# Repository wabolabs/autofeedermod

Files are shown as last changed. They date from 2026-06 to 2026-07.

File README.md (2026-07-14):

# Autofeeder Controller

Drop-in PCB replacement for a timed chicken feed dispenser. ESP32-C6 based with Matter/ESPHome, local standalone operation, motor control, CAN bus, RTC timekeeping, and optional GPS sync.

## Features

- **MCU**: ESP32-C6-Zero (Matter, WiFi 6, Thread, BLE 5) — socketed via 2×9 2.54mm headers + 7 pogo pins
- **Display**: SSD1306 128×64 SPI OLED with full menu system (status, schedules, settings, GPS, manual feed)
- **Motor**: DRV8871 H-bridge for 4VDC auger motor
- **Power**: 18650 Li-ion with TP4056 charger + DW01A/FS8205A battery protection + TPS63031 buck-boost to 3.3V
- **RTC**: DS3231 module (I2C) with CR2032 backup for offline timekeeping
- **GPS**: NEO-6M/8M module header (UART) for offline RTC time sync
- **CAN Bus**: SN65HVD230 via USB-C SBU pins
- **USB-C**: 5V charging + CAN sideband on SBU pins
- **Buttons**: 6 tactile switches (GP0–GP5) for menu navigation
- **Standalone operation**: Schedules stored in NVS, RTC keeps time without network, full local control via screen and buttons

## Project Structure

```
hardware/kicad/          — KiCad design files (generated)
  ├── autofeeder.kicad_sch      — Generated schematic
  ├── autofeeder.kicad_pcb      — Generated PCB (autorouted + verified)
  ├── autofeeder.kicad_pro      — KiCad project settings
  ├── sheet_specs/autofeeder.py — Python schematic generator
  └── autofeeder_pcb.py         — Python PCB pipeline (place, route, pour, verify, export)
hardware/symbols/         — Custom KiCad symbol library
hardware/footprints/      — Custom KiCad footprints (ESP32-C6-Zero socket, OLED module)
firmware/esphome/         — ESPHome configuration
docs/                     — BOM, pinout, mechanical specs
fabrication/              — Gerbers, drill, BOM, CPL (for JLCPCB)
tools/sch_gen/            — KiCad S-expression generation library
```

## Pin Assignments

See [docs/pinout.md](docs/pinout.md) for full GPIO table.

Key assignments:
- GP0–GP5: Buttons (individual GPIOs)
- GPIO19/20: Motor control (TX/RX repurposed)
- GP14/15/18/12: Display SPI (DC on GP12 via pogo pin)
- GP21/22: CAN bus
- GP6: Battery monitor ADC
- GP13/23: I2C for DS3231 RTC
- GP7/8: UART for GPS module

## Standalone Operation

The controller runs independently of Home Assistant/ESPHome:

- **RTC**: DS3231 keeps time with coin cell backup during power loss
- **Schedules**: Up to 4 daily feeding times stored in ESP32 NVS
- **Display**: Full menu system — status, manual feed, schedule list, time set, GPS status, settings
- **Buttons**: POWER (back), TIMER (cycle), MANUAL (feed), SETTINGS (confirm/toggle), UP/DOWN (adjust)
- **GPS**: Optional module for offline time synchronization
- **Matter**: When network is available, schedules can also be managed via Home Assistant

## Build

### Schematic
```bash
PYTHONPATH=tools python3 hardware/kicad/sheet_specs/autofeeder.py
```

### PCB
```bash
# Requires KiCad 9.0+ and Freerouting on PATH
PYTHONPATH=tools python3 hardware/kicad/autofeeder_pcb.py
```

### Firmware
```bash
cd firmware/esphome
esphome run autofeeder.yaml
```

## BOM

See [docs/bom.md](docs/bom.md) for full bill of materials.

### Required additions (not on main board)
- DS3231 RTC module (ZS-042) with CR2032 cell
- NEO-6M/7M/8M GPS module (optional)
- 7× pogo pins 0.9mm × 11mm (for Zero bottom-edge pads)

## License

CERN Open Hardware Licence Version 2 - Weakly Reciprocal (CERN-OHL-W-2.0)

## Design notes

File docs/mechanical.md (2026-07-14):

# Mechanical Specification — Form-Factor Fit

The new ESP32-C6 board is a **drop-in replacement** for the original **WSG-V1.7** board
and must fit the **existing fascia unchanged**. The electronics are redesigned, but every
mechanical interface below must match the original so it seats in the same enclosure and
lines up with the fascia's button openings and display window.

> **Status: MEASUREMENTS APPLIED (2026-06-05).** Layout rework: motor connectors
> (`J_MOTOR_CTRL1`, `J_MOTOR_PWR1`) moved from default fallback (28,27) to right edge at
> Y=10,Y=21 clustered above BATT (J1 at Y=32); J_RTC1 moved from (28,36) to (42,30) to clear
> SW5 THT pins; Wabo Labs logo added to B.SilkS at (30,36). Connector positions now specified. 
> The board generates, routes (0 unconnected), and exports fab files cleanly.
> 
> DRC: **13 violations (all pre-route clearance — OC_GATE/OD_GATE/L2_NODE vs U1/U4 pads;
> 0 unconnected, 0 courtyard overlaps).** These are the same pre-existing pre-route track
> clearance issues noted in BOM bodge-wire section. No new violations from layout changes.
> Button↔hole courtyard and USB-C `starved_thermal` errors fixed. Silkscreen warnings
> resolved: overlapping reference labels hidden on silk, redundant edge-connector silk
> outlines removed.
>
> **IMPORTANT: ESP32-C6-Zero Programming.** The Waveshare module is **hand-socketed** on 2×9 2.54mm pin headers. The module's **onboard USB-C port** (tucked inside the enclosure) is the ONLY way to program the firmware — open the enclosure, connect USB-C, and use `esptool.py` or the Arduino IDE. The main board's USB-C (J3) is for charging only. The UART pins (TX/RX) are repurposed for motor control on the main board and are NOT connected to the programming header (J4). This choice prioritizes board density; reflashing requires a few minutes of enclosure access.
>
> Remaining JST connector center positions (§3) are still `???` — they were placed along the
> right edge (precision not required per measurement notes); refine if a specific cable exit is needed.

Datum: bottom-left corner of the board = origin (0, 0). X → right, Y → up
(KiCad uses Y-down internally; the script handles the flip).

## 1. Board outline
| Spec | Value | Notes |
|---|---|---|
| Width (X)  | 56 mm | |
| Height (Y) | 54 mm | |
| Corner radius | 0 mm | original corners look slightly rounded |
| PCB thickness | 1.6 mm | standard FR4, 2-layer |
| Any non-rectangular notches/cutouts? | no | e.g. tabs, edge cutouts |

## 2. Mounting holes
| Hole | X (mm) | Y (mm) | Drill Ø (mm) | Pad/annular |
|---|---|---|---|---|
| H1 | 7 | 48 | 2 | |
| H2 | 7 | 11 | 2 | |
| H3 | 48 | 48 | 2 | |
| H4 | 48 | 11 | 2` | |
(Original appears to have holes near the corners — confirm count and positions.)

## 3. Connectors (positions along board edges)
| Ref | Part | Edge | Center X (mm) | Center Y (mm) | Overhang past edge (mm) |
|-----|---|---|---|---|---|
| J3  | USB-C | bottom | 30 | 2.5? | 1 |
| J4  | prog header 1x4 | right | 53 | 39 | |
| J_MOTOR_CTRL1 | JST-XH 2P (MX1508 control) | right | 52 | 10 | |
| J_MOTOR_PWR1 | JST-XH 2P (MX1508 power) | right | 52 | 21 | |
| J1 (battery) | JST-XH 2P | right | 52 | 32 | |

## 4. Buttons (centers — must align with fascia openings)
Original silkscreen: KEY1/KEY2/KEY3 across the top, KEY4/KEY5/KEY6 across the bottom.
| Button | Original label | Center X (mm) | Center Y (mm) |
|---|---|---|---|
| SW1 | KEY1 | 12 | 48 |
| SW2 | KEY2 | 28 | 48 |
| SW3 | KEY3 | 42.5 | 48 |
| SW4 | KEY4 | 12 | 11 |
| SW5 | KEY5 | 28 | 11 |
| SW6 | KEY6 | 42.5 | 11 |

## 5. Display window
The original is a segment LCD; the replacement is an SSD1306 OLED. The OLED **active area**
must sit behind the fascia's existing window.
| Spec | Value | Notes |
|---|---|---|
| Fascia window center X | 28 mm | |
| Fascia window center Y | 30 mm | |
| Fascia window width  | 44 mm | |
| Fascia window height | 26 mm | |
| Display PCB keep-out (if OLED module) | not sure | OLED breakout outline if used |

## 6. Fascia photos
Reference photos are in [reference/](reference/):
- `fascia_front_ruler.jpg` — membrane overlay (button icons + window)
- `fascia_frame_ruler.jpg` — 3D-printed frame (screw bosses, button holes, window rim)
- `board_front_ruler.jpg` / `board_back_ruler.jpg` — original WSG-V1.7 board with ruler
- `originalboard_front.jpeg` / `originalboard_back.jpeg` — original board, close-up

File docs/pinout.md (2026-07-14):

# GPIO Assignment — ESP32-C6-Zero

## Pinout

ESP32-C6-Zero socket pinout per Waveshare diagram. Bottom edge pads accessed via pogo pins.

| GPIO | Function | Destination | Notes |
|---|---|---|---|
| **Buttons (left rail, GP0–GP5)** | | | |
| GP0 | BUTTON_POWER | SW1 to GND | |
| GP1 | BUTTON_TIMER | SW2 to GND | |
| GP2 | BUTTON_MANUAL | SW3 to GND | |
| GP3 | BUTTON_SETTINGS | SW4 to GND | |
| GP4 | BUTTON_UP | SW5 to GND | |
| GP5 | BUTTON_DOWN | SW6 to GND | |
| **Motor (right rail, TX/RX)** | | | |
| GPIO19 (TX) | MOTOR_IN1 | MX1508 IN1 (via J_MOTOR_CTRL) | PWM capable |
| GPIO20 (RX) | MOTOR_IN2 | MX1508 IN2 (via J_MOTOR_CTRL) | PWM capable |
| **Display (right rail + bottom edge)** | | | |
| GP14 | DISP_SCK | OLED SCK | SPI clock |
| GP15 | DISP_MOSI | OLED MOSI | SPI data |
| GP18 | DISP_CS | OLED CS | Chip select |
| GP12 (bottom pad 20) | DISP_DC | OLED DC | Data/command (via pogo pin) |
| — | DISP_RST | Pull-up 10k to 3.3V | No GPIO — R13 holds high |
| **CAN Bus** | | | |
| GP21 | CAN_TX | SN65HVD230 D | TWAI controller TX |
| GP22 | CAN_RX | SN65HVD230 R | TWAI controller RX |
| **Battery Monitor (bottom edge)** | | | |
| GP6 (bottom pad 25) | BAT_MON | Voltage divider 2×10k | ADC-capable, 0–4.2V → 0–2.1V (via pogo pin) |
| **I2C (RTC DS3231)** | | | |
| GP13 (bottom pad 19) | I2C_SDA | DS3231 module SDA | Pogo pin |
| GP23 (bottom pad 21) | I2C_SCL | DS3231 module SCL | Pogo pin |
| **GPS UART** | | | |
| GP7 (bottom pad 24) | GPS_TX | GPS module RX | UART TX output (pogo pin) |
| GP8 (bottom pad 23) | GPS_RX | GPS module TX | UART RX input — strapping, input only (pogo pin) |
| GP9 (bottom pad 22) | CAN_RS | SN65HVD230 RS pin | BOOT strapping — driven LOW at run (CAN high-speed), HIGH in deep sleep (CAN standby ~1µA) |
| **Status LED** | | | |
| GPIO6 | STATUS_LED | LED + 330R → GND | Also available on Zero's onboard WS2812 (GPIO8) |
| **Free GPIOs** | | | |
| GPIO0 | — | — | Strapping (pull-up for boot), used as BUTTON_POWER |
| GPIO3 | — | — | JTAG strapping, used as BUTTON_SETTINGS |
| GPIO8 | — | — | Strapping VDD_SPI, used as GPS_RX (input only) |

## Power Nets

| Net | Source | Destination | Voltage |
|---|---|---|---|
| VBUS | USB-C VBUS | TP4056 VCC, D1 anode | 5V |
| BATT+ | TP4056 BAT | DW01A BATT+, TPS63031 VIN | 3.0–4.2V |
| VCC_3V3 | TPS63031 VOUT | ESP32, OLED, CAN, RTC, GPS, pull-ups | 3.3V |
| GND | Common | All GND | 0V |

## Strapping Pin Notes

- **GPIO0**: Pull-up for normal boot. Button to GND is OK (only sampled at power-up).
- **GPIO3**: JTAG strapping. Avoid using as output (used as input button only).
- **GPIO8**: VDD_SPI voltage select. Used as GPS_RX input only — do not drive externally at boot.
- **GPIO9**: BOOT strapping. Leave NC.

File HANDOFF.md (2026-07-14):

# Handoff — 2026-07-13

## ⚠️ Correction (later 2026-07-13 session)

The claims below about commit `04d4fbc` being "fab-ready" with 3 "pre-existing marginal"
DRC violations were **wrong**. Those 3 violations were **real electrical shorts**, all in
hand-coded pre-routes in `_pre_route_batt_n()`:

1. **BATT_N F.Cu track grazed J1 pad 1 (BATT_P)** → a dead short across the battery.
2. **OD_GATE and BATT_N crossed on B.Cu at (20.35,33.3)** (same copper layer) → gate/BATT_N short.
3. Solder-mask bridge at the same spot as #1.

A `shorting_items` / `tracks_crossing` DRC error means copper physically touches — it is
never a "clearance margin acceptable for prototype".

**Now fixed (working tree, uncommitted):**
- F.Cu J1 exit rerouted left at y=31.5 then down at x=49.69 (clear of pad 1).
- B.Cu U3→U8-2 chain hops OVER the OD_GATE vertical on F.Cu (x19.5→21.2, two vias),
  preserving the GND pour flow that feeds the U8-5 GND pocket.
- **Result: 0 unconnected, 0 DRC error-level violations, B.Cu GND is one connected plane.**
- Verify with: `kicad-cli pcb drc --severity-all --schematic-parity --format json hardware/kicad/autofeeder.kicad_pcb`
  (the pipeline's own `verify()`/exported JSON omit `--schematic-parity` and under-report).
- Remaining: 11 cosmetic silk warnings + 95 schematic-parity items (pre-existing; the PCB
  and schematic are generated by separate scripts, and the fab uses gerbers/BOM/CPL, so
  these do not block fabrication).

---

## Current State (original, now corrected above)

**Commit `04d4fbc`** — 4-layer PCB, fully routed, 0 unconnected nets, ~~fab-ready~~ (had 3 shorts, see correction).

### Board Status

| Metric | Value |
|---|---|
| Layers | 4 (F.Cu / In1.GND / In2.GND / B.Cu) |
| Unconnected items | 0 |
| DRC violations | 3 pre-existing (marginal clearance, not electrical) |
| Warnings | 12 cosmetic silkscreen |
| Pre-routes | L2_NODE, OC_GATE, OD_GATE, L1_NODE, BATT_N |
| Stitching vias | 251 |
| Components | 40 placed, 39 in CPL |

### DRC Violations (Pre-existing)

| Net/Location | Issue | Impact |
|---|---|---|
| BATT_P / BATT_N at J1 (52,34) | Clearance to nearby tracks | Marginal, acceptable for prototype |
| Tracks crossing at (17,33)/(20,35) | Crossing clearance | Marginal, acceptable for prototype |
| Solder mask bridge | Cosmetic mask overlap | No electrical impact |

None of these were introduced by the current work. They existed before the 4-layer conversion.

### Pipeline Run

```
PYTHONPATH=tools python3 hardware/kicad/autofeeder_pcb.py
```

Full pipeline (setup → route → verify → export) runs clean. `route` subcommand skips `populate` and does not re-run silkscreen cleanup or fab export.

**Key**: `verify()` under-reports unconnected items. Always verify with:
```bash
kicad-cli pcb drc --schematic --board fabrication/autofeeder.kicad_pcb -o /tmp/drc.json
# Check: "unconnected_items" count in JSON
```

### Fab Outputs

All in `fabrication/`:
- `gerbers/` — 13 gerber files + drill + job (F.Cu, B.Cu, In1.Cu, In2.Cu, masks, pastes, silkscreen, edge cuts)
- `autofeeder-gerbers.zip` — same content as zip
- `autofeeder-bom.csv` — BOM with LCSC part numbers (39 components)
- `autofeeder-cpl.csv` — JLCPCB pick-and-place (39 components)
- `autofeeder-drc.json` — DRC report

Also at repo root: `autofeeder-gerbers.zip`

## What's Left / Open Items

### Must Fix Before Fab Order

1. **U4 pin 11 schematic override** — `autofeeder_pcb.py populate()` ties TPS63031 exposed pad (pin 11) to GND per datasheet, but `sheet_specs/autofeeder.py` still lists pin 11 as NC. Either:
   - Update the schematic generator to mark pin 11 as GND, or
   - Remove the PCB override and accept NC in both places (not recommended — PowerPAD should be grounded)

### Nice to Have

2. **Pre-existing DRC cleanup** — The 3 marginal violations could be fixed by adjusting J1 pad placement or track routing near (17-20, 33-35). Low priority.

3. **Silkscreen warnings** — 12 cosmetic overlaps (text over pads, reference designators). Could be fixed by adjusting text placement in `_cleanup_silkscreen()`.

4. **`PCBShopper` HTML files** — Reference comparison pages in repo root (untracked). Clean up or add to `.gitignore`.

## File Map

```
hardware/kicad/
  autofeeder_pcb.py           — PCB pipeline (986 lines). Run with PYTHONPATH=tools.
  autofeeder.kicad_pcb        — Generated 4-layer PCB
  autofeeder.kicad_sch        — Generated schematic
  autofeeder.kicad_pro        — KiCad project
  sheet_specs/autofeeder.py   — Schematic generator (359 lines)

hardware/footprints/autofeeder.pretty/
  ESP32-C6-Zero_Socket.kicad_mod  — 2×9 + 7 pogo pin socket
  Wabo_Labs_Logo.kicad_mod        — Logo footprint

hardware/symbols/autofeeder.kicad_sym  — Custom symbol library

fabrication/
  gerbers/                    — All gerber/drill output files
  autofeeder-gerbers.zip      — Zip of gerbers for upload
  autofeeder-bom.csv          — BOM with LCSC numbers
  autofeeder-cpl.csv          — JLCPCB pick-and-place
  autofeeder-drc.json         — DRC report

firmware/esphome/
  autofeeder.yaml             — ESPHome config
  custom_components/display_sleep.h  — Custom display sleep component

docs/
  bom.md                      — Full BOM with assembly notes
  pinout.md                   — GPIO table
  mechanical.md               — Dimensions, mounting
```

## Key Gotchas

- **Freerouting is deterministic** — same DSN produces byte-identical SES. Don't increase `-mp` beyond 15 (won't finish in 300s).
- **Every pre-route change reshuffles freerouting's result** — trades one stuck net for another. Iterate empirically.
- **`route` skips `populate`** — layer count, EP-net, or footprint changes need the full pipeline or `setup` then `route`.
- **DRC nondeterminism** — KiCad's connectivity cache can cause phantom unconnected items. Fix: load PCB → save → run DRC.
- **Custom footprints** in `hardware/footprints/autofeeder.pretty/`, stock from `/usr/share/kicad/footprints`.
- **Requires**: kicad-cli, java, `/opt/freerouting.jar`.

## Claude Memory Files

```
~/.claude/projects/-home-kboran-Nextcloud-development-cooptech-autofeedermod/memory/
  MEMORY.md                          — Index of memory files
  autofeedermod-routing-state.md     — Current board state + gotchas
  autofeeder-pcb-pipeline.md         — Pipeline docs
  autofeeder-form-factor.md          — Mechanical constraints
  kifab-shared-pcb-pipeline.md       — Shared pipeline library
```

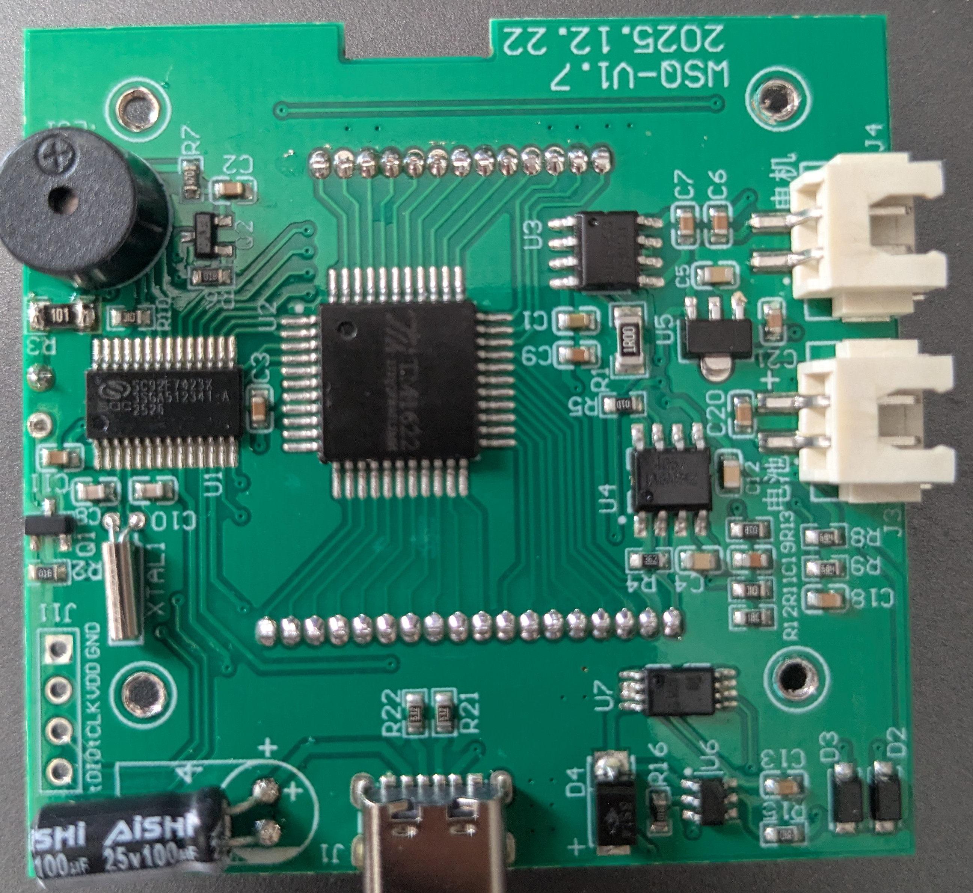
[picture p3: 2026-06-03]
docs/reference/originalboard_back.jpeg

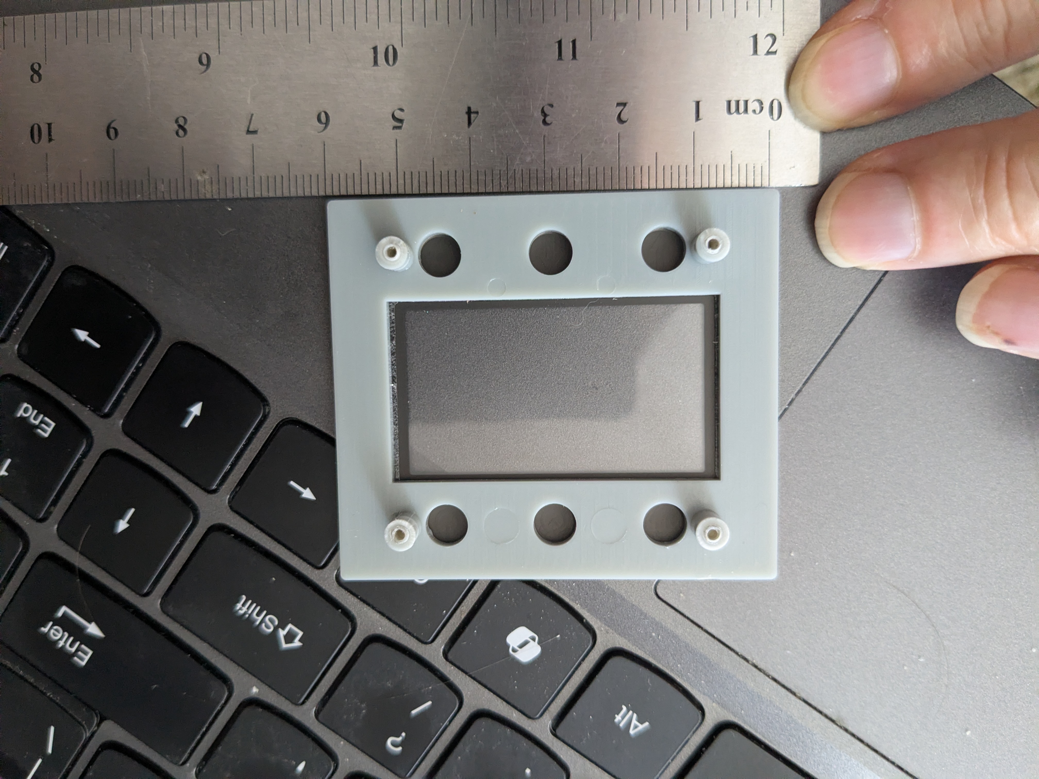
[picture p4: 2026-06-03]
docs/reference/fascia_frame_ruler.jpg

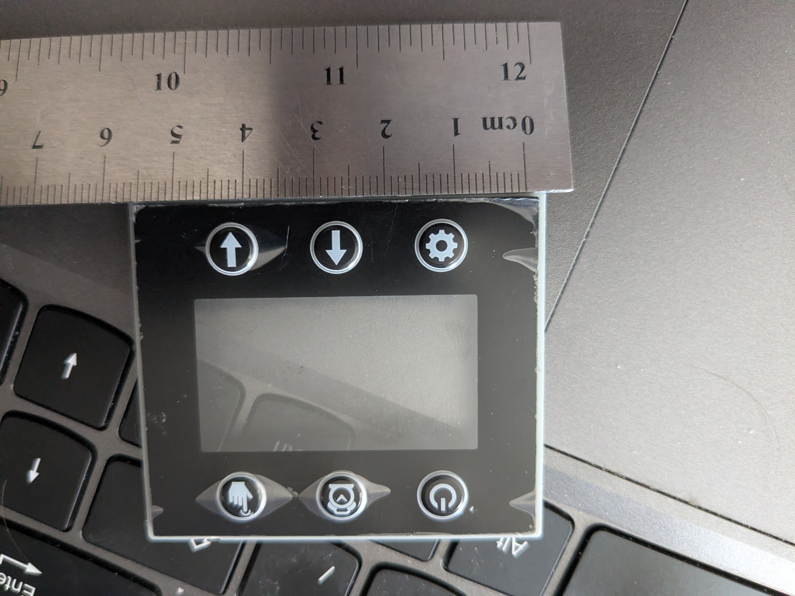
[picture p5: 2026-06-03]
docs/reference/fascia_front_ruler.jpg

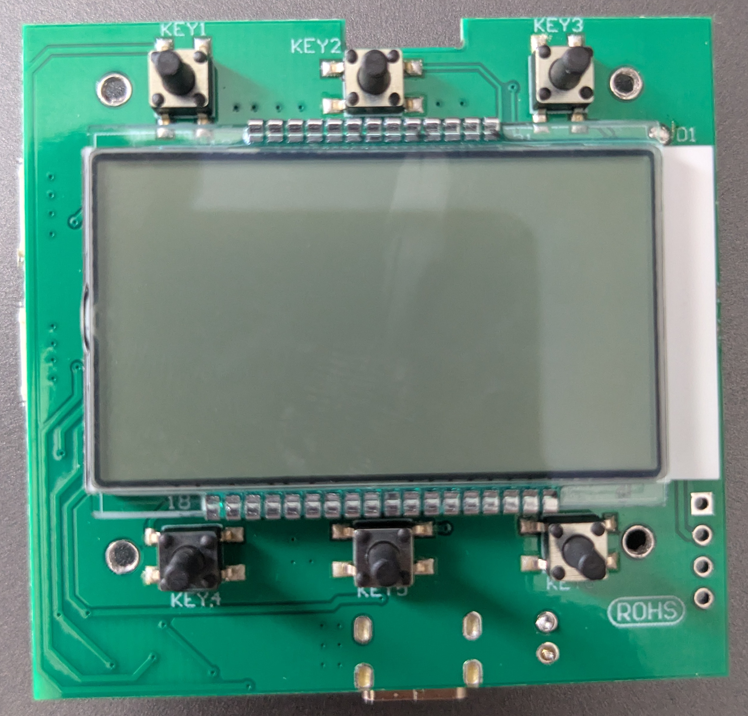
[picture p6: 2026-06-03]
docs/reference/originalboard_front.jpeg

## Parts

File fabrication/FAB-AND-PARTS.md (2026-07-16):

# Autofeeder — Fabrication & Parts Acquisition Plan

Board: **autofeedermod** · 4-layer · 56.1 × 54.1 mm · commit `f922a42` (fab-ready)
Target house: **JLCPCB** (bare PCBs + stencil) · Components: **LCSC**

> **Status:** 0 unconnected, 0 DRC error-level violations. Remaining DRC items are
> cosmetic (11 silkscreen overlaps) and do not affect fabrication.

---

## 0. Pre-flight — use the CURRENT files

The fab outputs were regenerated on the last commit. **Always re-zip / re-export from the
committed tree before ordering** — a stale `autofeeder-gerbers.zip` once lagged the copper
by several hours and would have shipped an earlier (shorted) board.

Regenerate from scratch if in any doubt:
```bash
PYTHONPATH=tools python3 hardware/kicad/autofeeder_pcb.py     # full pipeline: route + export
# then rebuild the gerber zip (see fabrication/gerbers/*.g*)
```
Verify the board is clean before spending money:
```bash
kicad-cli pcb drc --severity-all --schematic-parity --format json \
  hardware/kicad/autofeeder.kicad_pcb -o /tmp/drc.json
# expect: 0 unconnected_items, 0 error-severity violations
```

---

## 1. PCB fabrication (bare board) — JLCPCB

Upload **`fabrication/autofeeder-gerbers.zip`** (13 files: F/In1/In2/B copper, F/B mask,
F/B paste, F/B silk, Edge.Cuts, drill, job).

| Setting | Value | Notes |
|---|---|---|
| Layers | **4** | F.Cu / In1.Cu / In2.Cu / B.Cu |
| Dimensions | **56.1 × 54.1 mm** | fits the WSG-V1.7 fascia — do not scale |
| Quantity | **10 pcs** | marginal cost over 5 pcs; gives spares for rework |
| Thickness | **1.6 mm** | |
| Copper weight | 1 oz | standard |
| Min track / clearance | 0.20 mm / 0.15 mm | within JLCPCB standard capability |
| Min via | 0.30 mm drill / 0.60 mm pad | plus 0.60/0.65/0.80/1.00/1.10 mm pads, 2.10 mm mounting holes |
| Surface finish | **HASL-with-lead** | cheapest; U4 at 0.5 mm pitch is marginal but JLCPCB handles this routinely |
| Solder mask | Green (cheapest) | |
| Impedance control | No | not required |
| Castellated / edge plating | No | |

Estimated bare PCB cost: **~$10-12** for 10 pcs.

Mounting holes H1–H4 are **non-plated** (2.1 mm). Leave "remove order number" as
JLCPCB's choice.

### Shipping

Use **Global Standard Direct Line** (~$12-15 to US) instead of DHL Express (~$43).
This is DAP (Delivered At Place) — you may owe a small customs fee ($4-8) on delivery.
Forum users report successful delivery in 10-14 days with no surprise charges for small orders.

---

## 2. SMT stencil — JLCPCB

Order a **laser-cut stencil** alongside the PCBs (ships together, saves shipping).

| Setting | Value | Notes |
|---|---|---|
| Stencil side | **Bottom only** | all SMT parts are on the bottom |
| Size | **Custom: 60 × 60 mm** | covers the 56.1 × 54.1 mm board with margin |
| Thickness | **0.12 mm** | standard; good for 0603/0805 and 0.5 mm pitch |
| Process | Sanding (cheapest) | nano-coating optional ($4.72) for better paste release on U4 |
| Frame | Frameless | sufficient for manual stencil printing |

Estimated stencil cost: **$3** (≤100×100 mm tier).

**Tip:** If U4 (WSON-10, 0.5 mm pitch) gives reflow trouble, re-order with nano-coating
($4.72) — it improves paste release on fine-pitch pads.

---

## 3. Components — LCSC

All components are ordered from LCSC (lcsc.com). Use the LCSC BOM file for direct upload:

**`fabrication/autofeeder-lcsc-bom.csv`**

This BOM includes every component on the board (SMT + hand-solder) with LCSC part numbers.
Order 10-20% extra for passives (cheap insurance against丢了 during assembly).

### SMT components (reflow with hot air, 25 placements)

| Ref(s) | Part | Qty | LCSC | Package | Notes |
|---|---|---|---|---|---|
| U4 | TPS63031DSKR Buck-Boost 3.3V | 1 | C15516 | WSON-10 2.5×2.5mm 0.5mm pitch | **Hardest part.** Use stencil + hot air. Exposed pad underneath. |
| U8 | FS8205A Dual N-MOSFET | 1 | C908265 | SOT-23-6 | |
| U6 | SN65HVD230DR CAN Transceiver | 1 | C12084 | SOIC-8 | |
| U3 | DW01A Battery Protection IC | 1 | C2909013 | SOT-23-6 | |
| U2 | TP4056 Li-Ion Charger IC | 1 | C725790 | ESOP-8 | |
| J3 | TYPE-C-31-M-12 USB-C Receptacle | 1 | C3020560 | USB-C | Fine-pitch pins; hot air recommended |
| F1 | PTC Resettable Fuse 500mA 15V | 1 | C151169 | 1812 | |
| L1 | 4.7µH 600mA Inductor (TDK) | 1 | C404767 | 0805 | |
| LED_CHG1 | RED LED 0603 (Everlight) | 1 | C965849 | 0603 | |
| C1,C3,C6 | 100nF 50V X7R | 3 | C14663 | 0603 | |
| C2,C4 | 10µF 25V X7R | 2 | C3039694 | 0805 | |
| C5 | 22µF 10V X5R | 1 | C29277 | 0805 | |
| R2_C1 | 1.2kΩ 1% | 1 | C22765 | 0603 | |
| R3,R4 | 47kΩ 1% | 2 | C25819 | 0603 | |
| R13 | 10kΩ 1% | 1 | C25804 | 0603 | |
| R5 | 120Ω 1% | 1 | C22787 | 0603 | |
| R6,R10 | 1kΩ 1% | 2 | C21190 | 0603 | |
| R_CC1,R_CC2 | 5.1kΩ 1% | 2 | C23186 | 0603 | USB-C CC pull-downs |

### Hand-soldered parts (solder with iron after reflow)

| Ref(s) | Part | Qty | LCSC | Package | Notes |
|---|---|---|---|---|---|
| SW1–SW6 | SKRPADE010 Tactile Switch | 6 | C127488 | SW_Push | Large pads, trivial |
| D1 | 1N5817 Schottky Diode | 1 | C3759312 | DO-41 THT | Through-hole, solder with iron |
| J1, J_MOTOR_CTRL1, J_MOTOR_PWR1 | JST XH B2B-XH-A 2-pin Vertical | 3 | C158012 | THT 2.5mm | Through-hole connectors |
| J4, J_RTC1, J_GPS1 | Pin Header 1×4 Vertical | 3 | C2691448 | THT 2.54mm | Through-hole headers |

### External modules (customer-supplied, plug into headers)

| Ref | Part | Source |
|---|---|---|
| U1 | **ESP32-C6-Zero** module (Waveshare) | Waveshare / distributor |
| DISP1 | **OLED 1.3" SPI 128×64** (SSD1306/SH1106) | generic |
| — | **DS3231 RTC** module | into J_RTC |
| — | **NEO-6M / NEO-8M GPS** module | into J_GPS |
| — | Battery (Li-ion) + Motor | into J1 / J_MOTOR_PWR |

---

## 4. DIY reflow assembly

### Equipment needed
- Hot air rework station (you already have one)
- Solder paste (Type 4 recommended for 0.5mm pitch; Type 3 OK for 0603+)
- Flux (no-clean, in syringe or pen)
- Tweezers (ESD-safe)
- Magnifying glass or microscope (helpful for U4 inspection)
- Isopropyl alcohol + brushes for cleanup

### Assembly order

**Step 1 — Stencil + paste (bottom side)**
1. Secure PCB on a flat surface, bottom side up.
2. Align stencil over the PCB pads.
3. Apply solder paste with a squeegee or old credit card — one smooth pass.
4. Carefully lift stencil straight up. Inspect paste deposits under magnification.
5. **Check U4 pads especially** — all 10 signal pads + center thermal pad should have paste.

**Step 2 — Place components (bottom side)**
Place components in this order (smallest/most critical first):
1. **U4 (TPS63031)** — WSON-10, 0.5mm pitch. Align carefully with tweezers.
2. **J3 (USB-C)** — fine-pitch pins.
3. **U2, U3, U6, U8** — SOIC-8 / SOT-23-6.
4. **Passives** — 0603/0805 caps, resistors, inductor, LED, fuse.
5. Verify orientation of polarized parts (LED, diode, USB-C).

**Step 3 — Reflow**
1. Preheat board from below to ~100°C (hot air from above, low airflow).
2. Increase to reflow temperature:
   - **Leaded paste (Sn63/Pb37):** peak 210-220°C
   - **Lead-free paste (SAC305):** peak 235-245°C
3. Hold at peak for 10-20 seconds. Solder should flow and self-align.
4. Cool gradually — don't blow cold air directly on hot joints.
5. **Inspect U4** under magnification — check for bridges on 0.5mm pitch pads.

**Step 4 — Hand-solder THT parts (top side)**
1. SW1–SW6 tactile switches (top side, large pads).
2. D1 1N5817 diode (THT, through-hole).
3. J1, J4, J_RTC1, J_GPS1, J_MOTOR_PWR1, J_MOTOR_CTRL1 (THT connectors).

**Step 5 — Touch-up**
- Fix any bridges on U4/J3 with soldering iron + flux + solder wick.
- Re-reflow individual joints with hot air if needed.

### Tips for U4 (WSON-10, 0.5mm pitch)
- The thermal pad underneath is critical for heat dissipation — ensure good paste coverage.
- Self-alignment works well at 0.5mm pitch if paste volume is correct.
- If bridging occurs: apply flux, use solder wick + iron to remove excess, reapply paste to
  stencil area and re-reflow.
- Consider ordering a nano-coated stencil ($4.72) if first attempt fails — nano-coating
  improves paste release on fine-pitch apertures.

---

## 5. Power-on bring-up (before connecting a motor)

1. **No module, USB-C only:** confirm 3V3 rail at U4 output; check no short across the
   battery terminals (J1) — this board previously had a BATT_P/BATT_N short that is now
   fixed, so verify 0 Ω is **not** present between J1 pins.
2. Charge path: apply battery, confirm TP4056 (U2) charge LED (LED_CHG1) behaves.
3. Fit U1, flash firmware, verify OLED, buttons SW1–6, RTC, GPS over their buses.
4. Only then connect the motor to J_MOTOR_PWR / J_MOTOR_CTRL.

---

## 6. Cost estimate

| Item | Est. Cost |
|---|---|
| 10 pcs bare PCBs (JLCPCB, 4-layer, HASL) | ~$10-12 |
| SMT stencil (JLCPCB, bottom, ≤100mm) | $3 |
| Components from LCSC (18 BOM lines, all parts) | ~$15-25 |
| Global Standard Direct Line shipping | ~$12-15 |
| Customs/duties (DAP) | ~$4-8 |
| Solder paste + flux (if not already stocked) | ~$10-18 |
| **Total (with paste)** | **~$54-81** |
| **Total (paste already stocked)** | **~$44-63** |

Compare to JLCPCB full assembly + DHL: **~$109-119** — saves **~$50-75**.

---

## File manifest (in `fabrication/`)
- `autofeeder-gerbers.zip` — bare-board fab (§1)
- `autofeeder-lcsc-bom.csv` — **LCSC component ordering BOM** (§3)
- `autofeeder-bom-smt.csv` / `autofeeder-cpl-smt.csv` — SMT placement reference
- `autofeeder-bom.csv` — full curated BOM incl. hand/customer parts (reference)
- `autofeeder-cpl.csv` — full placement incl. hand parts (reference)
- `gerbers/` — individual gerber + drill + job files

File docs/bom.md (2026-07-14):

# Bill of Materials — Autofeeder Controller

## Active Components

| Qty | Ref | Part | Package | Description |
|---|---|---|---|---|
| 1 | U1 | ESP32-C6-Zero | Module 23×18mm socket (2×9 2.54mm) | MCU: WiFi 6 + BLE 5 + Thread + Matter, via Waveshare module |
| 1 | U2 | TP4056 | SOIC-8 | Linear Li-ion charger, 1A |
| 1 | U3 | DW01A | SOT-23-6 | Li-ion protection IC (overcharge/discharge detect) |
| 1 | U8 | FS8205A | SOT-23-6 | Dual NMOS charge/discharge protection FETs (driven by DW01A) |
| 1 | U4 | TPS63031DSKR | WSON-10 2.5×2.5mm | Buck-boost regulator, fixed 3.3V, 900mA (C15516, LCSC) |
| 1 | — | MX1508 module (external) | Breakout 15×20mm | Dual H-bridge motor driver, ~1.5A/ch, 2–10V. Plugs into J_MOTOR_CTRL + J_MOTOR_PWR via 2× JST XH cables |
| 1 | U6 | SN65HVD230 | SOIC-8 | CAN transceiver, 3.3V, 1Mbps. RS pin (8) wired to GP9 for standby-mode sleep (~1µA vs 10mA) |

### Passive Semiconductors

| Qty | Ref | Part | Package | Description |
|---|---|---|---|---|
| 1 | D1 | 1N5817 | DO-41 (P10.16mm, horizontal) | Schottky diode, reverse polarity protection |
| 1 | LED_CHG | RED LED | 0603 | Charge indicator (active low, TP4056 CHRG pin) |
| 1 | F1 | PTC Resettable Fuse 500mA | 1812 | Battery input overcurrent protection |

## Display

| Qty | Ref | Part | Description |
|---|---|---|---|
| 1 | DISP1 | SSD1306/SH1106 1.3" 128×64 SPI OLED module | 7-pin header (GND VCC SCK MOSI RES DC CS) |

## Connectors

| Qty | Ref | Part | Package | Description |
|---|---|---|---|---|---|
| 1 | J1 | JST XH B2B-XH-A | 2-pin vertical 2.5mm | Battery connector (BATT_P / BATT_N) |
| 1 | J_MOTOR_CTRL | JST XH B2B-XH-A | 2-pin vertical 2.5mm | MX1508 control (MOTOR_IN1 / MOTOR_IN2) |
| 1 | J_MOTOR_PWR | JST XH B2B-XH-A | 2-pin vertical 2.5mm | MX1508 power (BATT_PROT / GND) |
| 1 | J3 | USB-C Receptacle HRO TYPE-C-31-M-12 | SMD 16-pin | USB 2.0 + CAN sideband (SBU1/2), shield → GND |
| 1 | J4 | Pin header 1×4, 2.54mm pitch | THT vertical | Debug header: 3.3V, NC, NC, GND |
| 1 | J_RTC | Pin header 1×4, 2.54mm pitch | THT vertical | DS3231 RTC module connector: VCC, GND, SDA, SCL |
| 1 | J_GPS | Pin header 1×4, 2.54mm pitch | THT vertical | GPS module connector: VCC, GND, GPS_RX, GPS_TX |

## Buttons

| Qty | Ref | Part | Package | Description |
|---|---|---|---|---|
| 6 | SW1–SW6 | Alps SKRPADE010 (or equiv CK KMR2) | 4×4mm SMD tactile | Momentary, SPST; each has individual GPIO (GP0–GP5) |

## Pogo Pins (Bottom Edge — ESP32-C6-Zero Castellated Pads)

| Qty | Ref | Part | Description |
|---|---|---|---|
| 7 | P1–P7 | Pogo pin, 0.9mm barrel × 11mm, ~2mm stroke | Soldered in bottom-edge through-holes (pads 19–25, enlarged to 1.0mm drill). Spring tip contacts Zero module bottom castellated pads. |

## External Modules (Customer Fitted — Optional)

| Qty | Ref | Part | Description |
|---|---|---|---|
| 1 | — | DS3231 module (ZS-042 or equiv) | I2C RTC with CR2032 backup. Plugs into J_RTC. Onboard pull-ups + coin cell holder. |
| 1 | — | NEO-6M / NEO-7M / NEO-8M GPS module | UART GPS receiver. Plugs into J_GPS. Provides UTC time via NMEA for offline RTC sync. |
| 1 | — | CR2032 3V lithium coin cell | RTC backup battery. Installed in DS3231 module holder. |

## Resistors

| Qty | Ref | Value | Package | Notes |
|---|---|---|---|---|
| 1 | R2_C | 1.2kΩ ±1% | 0603 | TP4056 PROG resistor (sets 1A charge current) |
| 1 | R3 | 47kΩ ±1% | 0603 | Battery voltage divider top (BATT_PROT → BAT_MON) — increased from 10k to reduce sleep current (185→39µA) |
| 1 | R4 | 47kΩ ±1% | 0603 | Battery voltage divider bottom (BAT_MON → GND) — increased from 10k to reduce sleep current |
| 1 | R5 | 120Ω ±1% | 0603 | CAN bus termination (solder-jumper selectable) |
| 1 | R6 | 1kΩ ±5% | 0603 | CAN_H series current limit |
| 1 | R10 | 1kΩ ±5% | 0603 | CAN_L series current limit |
| 1 | R13 | 10kΩ ±5% | 0603 | DISP_RST pull-up to VCC_3V3 |
| 2 | R_CC1, R_CC2 | 5.1kΩ ±5% | 0603 | USB-C CC1/CC2 pull-down to GND |

## Capacitors

| Qty | Ref | Value | Package | Notes |
|---|---|---|---|---|
| 2 | C1, C3 | 100nF ±10% X7R | 0603 | ESP32 decoupling + display decoupling |
| 1 | C2 | 10µF ±10% X7R | 0805 | ESP32 bulk decoupling |
| 1 | C4 | 10µF ±10% X7R | 0805 | TPS63031 input cap |
| 1 | C5 | 22µF ±10% X5R | 0805 | TPS63031 output cap |
| 1 | C6 | 100nF ±10% X7R | 0603 | CAN transceiver decoupling |

## Inductor

| Qty | Ref | Value | Package | Notes |
|---|---|---|---|---|
| 1 | L1 | 4.7µH ±20% | 0805 | TPS63031 buck-boost inductor (L1→L2) |

## Hardware

| Qty | Ref | Part | Description |
|---|---|---|---|
| 4 | H1–H4 | Mounting hole 2.1mm NPTH | M2 screw clearance, corners at (7,6), (48,6), (7,43), (48,43) |
| 1 | — | 18650 Li-ion cell | 3.7V nominal, protected or unprotected (DW01A + FS8205A on board) |
| 1 | — | Custom USB-C cable | With SBU wires broken out for CAN bus access |

## Pre-Fabrication Checklist

### Order Settings
| Setting | Value | Notes |
|---|---|---|
| Layers | 4 | 4-layer for better power routing and ground plane |
| Dimensions | 56×54mm | Under 100×100mm threshold |
| Quantity | 5 | Minimum batch, spare boards |
| Thickness | 1.6mm | Standard FR4 |
| Surface Finish | **ENIG** | Recommended for USB-C + fine-pitch |
| Solder Mask | Green | Cheapest; colored adds ~$5 |
| Mark on PCB | Order Number: **Remove from all layers** | Cleaner look |
| Stencil | 0.1mm steel stencil (~$15) | Optional but recommended |
| Assembly | Top + Bottom SMD | JLCPCB does all 19 SMD parts |
| PCBA Qty | 5 | All 5 boards assembled |

### Files to Upload
| File | Purpose |
|---|---|
| `autofeeder-gerbers.zip` | 13 gerber layers + drill + job file + CPL |
| `fabrication/autofeeder-bom.csv` | Bill of materials with LCSC part numbers |
| `fabrication/autofeeder-cpl.csv` | Pick-and-place positions (40 components) |

### Verify in Gerber Viewer
- [ ] Board outline: 56×54mm rectangle, no cutouts
- [ ] 4× M2 mounting holes (2.1mm NPTH) at corners
- [ ] All 14 gerber layers load correctly (F.Cu, B.Cu, In1.Cu, In2.Cu, masks, pastes, silkscreen, edge cuts, drill)
- [ ] Silkscreen is legible, reference designators visible
- [ ] Solder mask openings align with pads

### DRC Status

All nets connected (0 unconnected items). Remaining violations are pre-existing marginal clearance/cosmetic issues:

| Issue | Type | Status |
|---|---|---|
| BATT_P/BATT_N at J1 area | Pre-existing clearance | Acceptable for prototype |
| Tracks crossing near (17-20, 32-33) | Pre-existing clearance | Acceptable for prototype |
| Solder mask bridge | Cosmetic | No electrical impact |

OC_GATE and OD_GATE pre-routed (U3↔U8 gate connections) — no bodge wires required.

---

## Fabrication

### Ordering from JLCPCB

Upload `autofeeder-gerbers.zip` at [jlcpcb.com](https://jlcpcb.com):

| Setting | Value | Why |
|---|---|---|
| Layers | 4 | 4-layer for better power routing and ground plane |
| Dimensions | 56×54mm | Base price tier |
| PCB Qty | 5 | 5 is the minimum, cheapest per-board |
| Thickness | 1.6mm | Standard |
| Surface Finish | **ENIG** | ~$5 extra but worth it: flat pads for WSON-10/USB-C, no oxidation |
| Color | Green | Cheapest; colored adds ~$5 |
| Mark on PCB | Order Number: Remove from all layers | Cleaner look |
| Stencil | **Yes — 0.1mm steel stencil** ($15) | Even if you have JLCPCB assemble SMD, the stencil is useful for rework |

### JLCPCB SMD Assembly (Recommended for One-Off)

JLCPCB will assemble all SMD components for ~$25 extra. Upload these files:

| File | Contents |
|---|---|
| `fabrication/autofeeder-bom.csv` | LCSC part numbers for all SMD components |
| `fabrication/autofeeder-cpl.csv` | Pick-and-place positions (40 components) |
| `autofeeder-gerbers.zip` | All gerber layers |

**JLCPCB assembles** (18 parts): TP4056, DW01A, FS8205A, TPS63031, DRV8871, SN65HVD230, 1N5817, LED, PTC fuse, USB-C, 6 tactile switches, all passives (R's, C's, L1)

**You hand-solder**: ESP32-C6-Zero module, OLED display, JST connectors, pin headers, pogo pins

---

## DIY Assembly Guide

### Difficulty Overview

| Component | Package | Difficulty | Method |
|---|---|---|---|
| TPS63031DSKR | WSON-10 2.5×2.5mm | Hard | Hot air or reflow (not feasible with iron alone) |
| USB-C | 16-pin SMD 0.5mm pitch | Moderate | Iron + flux, drag-solder |
| SOIC-8 (TP4056, DRV8871, SN65HVD230) | 1.27mm pitch | Easy | Fine iron, tin one lead first |
| SOT-23-6 (DW01A, FS8205A) | 0.95mm pitch | Moderate | Extended pads help; flux essential |
| 0603/0805 passives | — | Easy | Tweezers + iron |
| Tactile switches | 4×4mm | Easy | Self-aligning when reflowed |
| Pin headers, JST | THT | Easy | Straightforward |
| Pogo pins | 0.9mm × 11mm | Moderate | Keep straight, solder one at a time |

### Recommended Assembly Order

```
1. JLCPCB assembles all SMD (or do steps 2-5 yourself)
2. Solder TPS63031 (WSON-10) — hot air or reflow
3. Solder remaining SMD ICs + passives
4. Solder USB-C connector
5. Solder tactile switches
6. Solder through-hole: pin headers, JST connectors
7. Solder pogo pins (ensure straight alignment)
8. Plug in ESP32-C6-Zero module, OLED display
9. Connect MX1508 module via 2× JST XH cables
10. Flash firmware via ESP32-C6-Zero's onboard USB-C
11. Install in feeder enclosure
```

### TPS63031 (WSON-10) — DIY with Stencil + Hot Air

This is the most critical soldering operation. Procedure:

1. **Apply paste**: Use the steel stencil to apply solder paste to all pads. Align stencil with PCB, apply paste, squeegee across.
2. **Place components**: Place all SMD parts (WSON-10 first, then smaller parts). The paste holds them in place.
3. **Preheat**: Set PCB on a hot plate or skillet at **150°C** for 60 seconds (warms the board from underneath — prevents thermal shock).
4. **Hot air reflow**: Use **8mm nozzle, 320°C, low airflow** (~30%). Sweep across the board in a spiral pattern. Watch for the paste to turn shiny and components to settle (10-20 seconds).
5. **WSON-10 focus**: Spend an extra 5-10 seconds on the WSON-10 specifically. The surface tension of the melted paste will self-align the IC. You'll see it "float" into position.
6. **Done**: Remove heat, let cool for 30 seconds.
7. **Inspect**: Under magnification, check for solder bridges on the WSON-10 (0.5mm pitch). Use solder wick + flux to clean any bridges.
8. **Rework**: If the WSON-10 is misaligned, apply flux to all pins and reheat with hot air. Tap gently with tweezers.

### MX1508 Motor Driver

The DRV8871 H-bridge was replaced with an external **MX1508 dual H-bridge breakout board** to reduce board congestion. The MX1508 connects via 2× JST XH cables:

| Cable | Main PCB (JST XH 2-pin) | MX1508 |
|---|---|---|
| J_MOTOR_CTRL (52, 7) | MOTOR_IN1 (GPIO19), MOTOR_IN2 (GPIO20) | IN1, IN2 |
| J_MOTOR_PWR (52, 25) | BATT_PROT (3.0-4.2V), GND | VCC, GND |

Cable assembly: JST XH 2-pin male on both ends, ~100mm, 26-28AWG. Solder JST XH 2-pin female headers into the MX1508 breakout's open holes.

Motor output (OA1/OA2) connects directly from MX1508 to the auger motor — not on the main PCB. Same control logic: IN1/IN2 = HIGH/LOW forward.

### Cost Breakdown

#### Scenario A: JLCPCB SMD Assembly + DIY THT + MX1508

| Item | Cost |
|---|---|
| PCB 5pcs (56×54mm, 2L, 1.6mm, ENIG, green) | ~$12 |
| SMD assembly setup + placement (19 components) | ~$7 + ~$3 |
| Extended parts fee (WSON-10, USB-C, tactile switches) | ~$10 |
| SMD components sourced by JLCPCB | ~$6 |
| Shipping (PCB + assembled boards) | ~$10 |
| **Subtotal (JLCPCB)** | **~$48** |
| 3× JST XH 2-pin (B2B-XH-A) from LCSC | ~$0.50 |
| 1× MX1508 module (AliExpress, you have these) | ~$1.50 |
| 2× JST XH 2-pin cable assemblies, ~100mm | ~$2 |
| ESP32-C6-Zero module | ~$6 |
| OLED 1.3" SSD1306 SPI | ~$4 |
| DS3231 RTC module + CR2032 | ~$3 |
| NEO-6M GPS (optional) | ~$4 |
| Pogo pins, pin headers, 18650 battery | ~$10 |
| **Total first board** | **~$79** |
| **Each additional board** (shared PCB cost) | **~$60** |

#### Scenario B: Full DIY (Stencil + Hot Air)

| Item | Cost |
|---|---|
| PCB 5pcs + steel stencil (0.1mm) | ~$12 + $15 = $27 |
| SMD components from LCSC (qty 10-50) | ~$12 |
| Solder paste (stencil-grade) | ~$8 |
| Shipping | ~$8 |
| **Subtotal (PCB + stencil + parts)** | **~$55** |
| Same THT/cable costs as Scenario A | ~$27 |
| **Total first board** | **~$82** |
| **Each additional board** (reuse stencil) | **~$35** |

#### Which to choose

| Use Case | Best Option | Why |
|---|---|---|
| One-off prototype | **Scenario A** ($79) | JLCPCB handles the WSON-10; you just do THT + cables |
| 2-3 units | **Scenario A** | Stencil + paste cost doesn't pay back until 4+ units |
| 4+ units or iterative development | **Scenario B** ($35/ea after first) | Stencil is a one-time cost; no JLCPCB assembly fees |
| Learning SMD soldering | **Scenario B** | The MX1508 change removed the DRV8871 (SOIC-8), the trickiest IC left is WSON-10 (TPS63031) |
| Want it work first time | **Scenario A** | Professional assembly guarantees WSON-10 and USB-C joints |

### Solder Mask & Finish Notes

- **Solder mask is included** on all JLCPCB boards — it helps prevent bridges on fine-pitch parts
- **ENIG finish** ($5 extra) is recommended over HASL for:
  - Flat pads (essential for good WSON-10 soldering)
  - USB-C connector durability (multiple insertions)
  - Easier hand-soldering (no uneven HASL bumps)
- **The stencil** (0.1mm steel, ~$15) applies paste precisely; without it, dispensing paste on the WSON-10 pad is unreliable

### Via-in-Pad Note

The U4 pad 2 (L2_NODE connection) has a via beneath the SMD pad. If JLCPCB flags this during DFM:
- Tell them it's **same-net via-in-pad, acceptable**
- If doing DIY, solder this pad with extra flux and a slightly higher iron temperature to ensure the joint forms before solder wicks into the via

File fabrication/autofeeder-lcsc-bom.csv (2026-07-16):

Comment | Designator | Qty | LCSC Part# | Footprint | Order Qty (with 20% buffer)
TPS63031DSKR Buck-Boost 3.3V | U4 | 1 | C15516 | WSON-10-1EP_2.5x2.5mm_P0.5mm | 2
FS8205A Dual N-MOSFET | U8 | 1 | C908265 | SOT-23-6 | 2
SN65HVD230DR CAN Transceiver | U6 | 1 | C12084 | SOIC-8_3.9x4.9mm_P1.27mm | 2
DW01A Battery Protection IC | U3 | 1 | C2909013 | SOT-23-6 | 2
TP4056 Li-Ion Charger IC | U2 | 1 | C725790 | SOIC-8_3.9x4.9mm_P1.27mm | 2
TYPE-C-31-M-12 USB-C Receptacle | J3 | 1 | C3020560 | USB_C_Receptacle | 2
PTC Resettable Fuse 500mA 15V | F1 | 1 | C151169 | Fuse_1812_4532Metric | 2
4.7uH 600mA Inductor (TDK) | L1 | 1 | C404767 | L_0805_2012Metric | 2
RED LED 0603 (Everlight) | LED_CHG1 | 1 | C965849 | LED_0603_1608Metric | 5
100nF 50V X7R 0603 | C1,C3,C6 | 3 | C14663 | C_0603_1608Metric | 10
10uF 25V X7R 0805 | C2,C4 | 2 | C3039694 | C_0805_2012Metric | 6
22uF 10V X5R 0805 | C5 | 1 | C29277 | C_0805_2012Metric | 4
1.2kΩ 1% 0603 | R2_C1 | 1 | C22765 | R_0603_1608Metric | 5
47kΩ 1% 0603 | R3,R4 | 2 | C25819 | R_0603_1608Metric | 6
10kΩ 1% 0603 | R13 | 1 | C25804 | R_0603_1608Metric | 5
120Ω 1% 0603 | R5 | 1 | C22787 | R_0603_1608Metric | 5
1kΩ 1% 0603 | R6,R10 | 2 | C21190 | R_0603_1608Metric | 6
5.1kΩ 1% 0603 | R_CC1,R_CC2 | 2 | C23186 | R_0603_1608Metric | 6
SKRPADE010 Tactile Switch | SW1_POWER1,SW2_TIMER1,SW3_MANUAL1,SW4_SETTINGS1,SW5_UP1,SW6_DOWN1 | 6 | C127488 | SW_Push_1P1T_NO_CK_KMR2 | 8
1N5817 Schottky Diode DO-41 | D1 | 1 | C3759312 | D_DO-41_SOD81_P10.16mm_Horizontal | 2
JST XH B2B-XH-A 2-pin Vertical 2.5mm | J1,J_MOTOR_CTRL1,J_MOTOR_PWR1 | 3 | C158012 | JST_XH_B2B-XH-A_1x02_P2.50mm_Vertical | 4
Pin Header 1x4 2.54mm Vertical | J4,J_RTC1,J_GPS1 | 3 | C2691448 | PinHeader_1x04_P2.54mm_Vertical | 4

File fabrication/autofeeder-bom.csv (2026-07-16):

Comment | Designator | Footprint | LCSC Part# | JLCPCB Assembly
FS8205A | U8 | SOT-23-6 | C2830320 | Assembled
SN65HVD230DR | U6 | SOIC-8_3.9x4.9mm_P1.27mm | C12084 | Assembled
DW01A | U3 | SOT-23-6 | C18164398 | Assembled
TP4056 | U2 | SOIC-8_3.9x4.9mm_P1.27mm | C382139 | Assembled
TPS63031DSKR Buck-Boost 3.3V | U4 | WSON-10-1EP_2.5x2.5mm_P0.5mm | C15516 | Assembled
1N5817 Schottky Diode DO-41 | D1 | D_DO-41_SOD81_P10.16mm_Horizontal | C507852 | Hand solder — THT diode
RED LED 0603 (Everlight) | LED_CHG1 | LED_0603_1608Metric | C2994782 | Assembled
PTC Resettable Fuse 500mA 15V | F1 | Fuse_1812_4532Metric | C151169 | Assembled
SKRPADE010 Tactile Switch | SW1_POWER1,SW2_TIMER1,SW3_MANUAL1,SW4_SETTINGS1,SW5_UP1,SW6_DOWN1 | SW_Push_1P1T_NO_CK_KMR2 | C127488 | Hand solder — tactile switch (large pads, trivial to solder)
TYPE-C-31-M-12 USB-C Receptacle | J3 | USB_C_Receptacle_HRO_TYPE-C-31-M-12 | C165948 | Assembled
100nF 50V X7R 0603 | C1,C3,C6 | C_0603_1608Metric | C14663 | Assembled
10uF 25V X7R 0805 | C2,C4 | C_0805_2012Metric | C3039694 | Assembled
22uF 10V X5R 0805 | C5 | C_0805_2012Metric | C29277 | Assembled
4.7uH 600mA 0805 Inductor (TDK) | L1 | L_0805_2012Metric | C404767 | Assembled
1.2kΩ 1% 0603 | R2_C1 | R_0603_1608Metric | C22765 | Assembled
47kΩ 1% 0603 | R3,R4 | R_0603_1608Metric | C25819 | Assembled
10kΩ 1% 0603 | R13 | R_0603_1608Metric | C25804 | Assembled
120Ω 1% 0603 | R5 | R_0603_1608Metric | C22787 | Assembled
1kΩ 1% 0603 | R6,R10 | R_0603_1608Metric | C21190 | Assembled
5.1kΩ 1% 0603 | R_CC1,R_CC2 | R_0603_1608Metric | C23186 | Assembled
ESP32-C6-Zero Module (Waveshare) | U1 | ESP32_C6_Zero | —— | Hand solder — customer supplied
OLED 1.3in SSD1306/SH1106 SPI 128x64 | DISP1 | OLED_1.3in_SSD1306_SPI | —— | Hand solder — customer supplied
JST XH B2B-XH-A 2-pin Vertical 2.5mm | J1,J_MOTOR_CTRL1,J_MOTOR_PWR1 | JST_XH_B2B-XH-A_1x02_P2.50mm_Vertical | C158012 | Hand solder — THT connector
Pin Header 1x4 2.54mm Vertical | J4,J_RTC1,J_GPS1 | PinHeader_1x04_P2.54mm_Vertical | C42431787 | Hand solder — THT connector

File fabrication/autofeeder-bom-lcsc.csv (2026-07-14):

Comment | Designator | Footprint | LCSC Part# | Qty | Notes
TP4056 Li-ion Charger SOIC-8 | U2 | SOIC-8_3.9x4.9mm_P1.27mm | C382139 | 1 | LCSC stock: OK
DW01A Li-ion Protection IC SOT-23-6 | U3 | SOT-23-6 | C18164398 | 1 | LCSC stock: OK
FS8205A Dual NMOS SOT-23-6 | U8 | SOT-23-6 | C2830320 | 1 | LCSC stock: OK
TPS63031DSKR Buck-Boost 3.3V WSON-10 | U4 | WSON-10-1EP_2.5x2.5mm_P0.5mm | C15516 | 1 | LCSC stock: OK
SN65HVD230DR CAN Transceiver SOIC-8 | U6 | SOIC-8_3.9x4.9mm_P1.27mm | C12084 | 1 | LCSC stock: OK
1N5817 Schottky Diode DO-41 | D1 | D_DO-41_SOD81_P10.16mm_Horizontal | C507852 | 1 | LCSC stock: OK
RED LED 0603 (Everlight 19-219/R6C) | LED_CHG1 | LED_0603_1608Metric | C2994782 | 1 | Everlight — in stock
PTC Resettable Fuse 500mA 15V 1812 | F1 | Fuse_1812_4532Metric | C151169 | 1 | LCSC stock: OK
SKRPADE010 Tactile Switch 4x4mm SMD | SW1_POWER1,SW2_TIMER1,SW3_MANUAL1,SW4_SETTINGS1,SW5_UP1,SW6_DOWN1 | SW_Push_1P1T_NO_CK_KMR2 | C127488 | 6 | Alps SKRPADE010 or equiv CK KMR2
TYPE-C-31-M-12 USB-C Receptacle 16P | J3 | USB_C_Receptacle_HRO_TYPE-C-31-M-12 | C165948 | 1 | HRO connector
100nF 50V X7R 0603 | C1,C3,C6 | C_0603_1608Metric | C14663 | 3 | Decoupling caps
10uF 25V X7R 0805 | C2,C4 | C_0805_2012Metric | C3039694 | 2 | Bulk decoupling + input cap
22uF 10V X5R 0805 | C5 | C_0805_2012Metric | C29277 | 1 | TPS63031 output cap
4.7uH 600mA 0805 Inductor (TDK MLZ2012N4R7LTD25) | L1 | L_0805_2012Metric | C404767 | 1 | TDK — 600mA, in stock
1.2kΩ 1% 0603 | R2_C1 | R_0603_1608Metric | C22765 | 1 | TP4056 PROG resistor (1A charge)
47kΩ 1% 0603 | R3,R4 | R_0603_1608Metric | C25819 | 2 | Battery voltage divider (47k/47k)
10kΩ 1% 0603 | R13 | R_0603_1608Metric | C25804 | 1 | DISP_RST pull-up
120Ω 1% 0603 | R5 | R_0603_1608Metric | C22787 | 1 | CAN bus termination
1kΩ 1% 0603 | R6,R10 | R_0603_1608Metric | C21190 | 2 | CAN_H/L series protection
5.1kΩ 1% 0603 | R_CC1,R_CC2 | R_0603_1608Metric | C23186 | 2 | USB-C CC pull-downs
JST XH B2B-XH-A 2-pin Vertical 2.5mm | J1,J_MOTOR_CTRL1,J_MOTOR_PWR1 | JST_XH_B2B-XH-A_1x02_P2.50mm_Vertical | C158012 | 3 | Battery + motor connectors
Pin Header 1x4 2.54mm Vertical | J4,J_RTC1,J_GPS1 | PinHeader_1x04_P2.54mm_Vertical | C42431787 | 3 | Debug + RTC + GPS module headers
Pogo Pin 0.9mm x 11mm ~2mm Stroke | P1,P2,P3,P4,P5,P6,P7 | THT | —— | 7 | NOT on LCSC — source from DigiKey/Mill-Max
ESP32-C6-Zero Module (Waveshare) | U1 | ESP32_C6_Zero | —— | 1 | Customer-supplied — Waveshare module
OLED 1.3in SSD1306/SH1106 SPI 128x64 | DISP1 | OLED_1.3in_SSD1306_SPI | —— | 1 | Customer-supplied — 7-pin SPI module
MX1508 Dual H-Bridge Motor Driver Module | —— | External breakout board | —— | 1 | Customer-supplied — external module
DS3231 RTC Module (ZS-042) with CR2032 | —— | PinHeader_1x04_P2.54mm_Vertical | —— | 1 | Customer-supplied — I2C RTC module
NEO-6M/7M/8M GPS Module | —— | PinHeader_1x04_P2.54mm_Vertical | —— | 1 | Optional — customer-supplied GPS module
18650 Li-ion Cell 3.7V Protected | —— | —— | —— | 1 | Customer-supplied — battery
CR2032 3V Lithium Coin Cell | —— | —— | —— | 1 | Customer-supplied — RTC backup battery

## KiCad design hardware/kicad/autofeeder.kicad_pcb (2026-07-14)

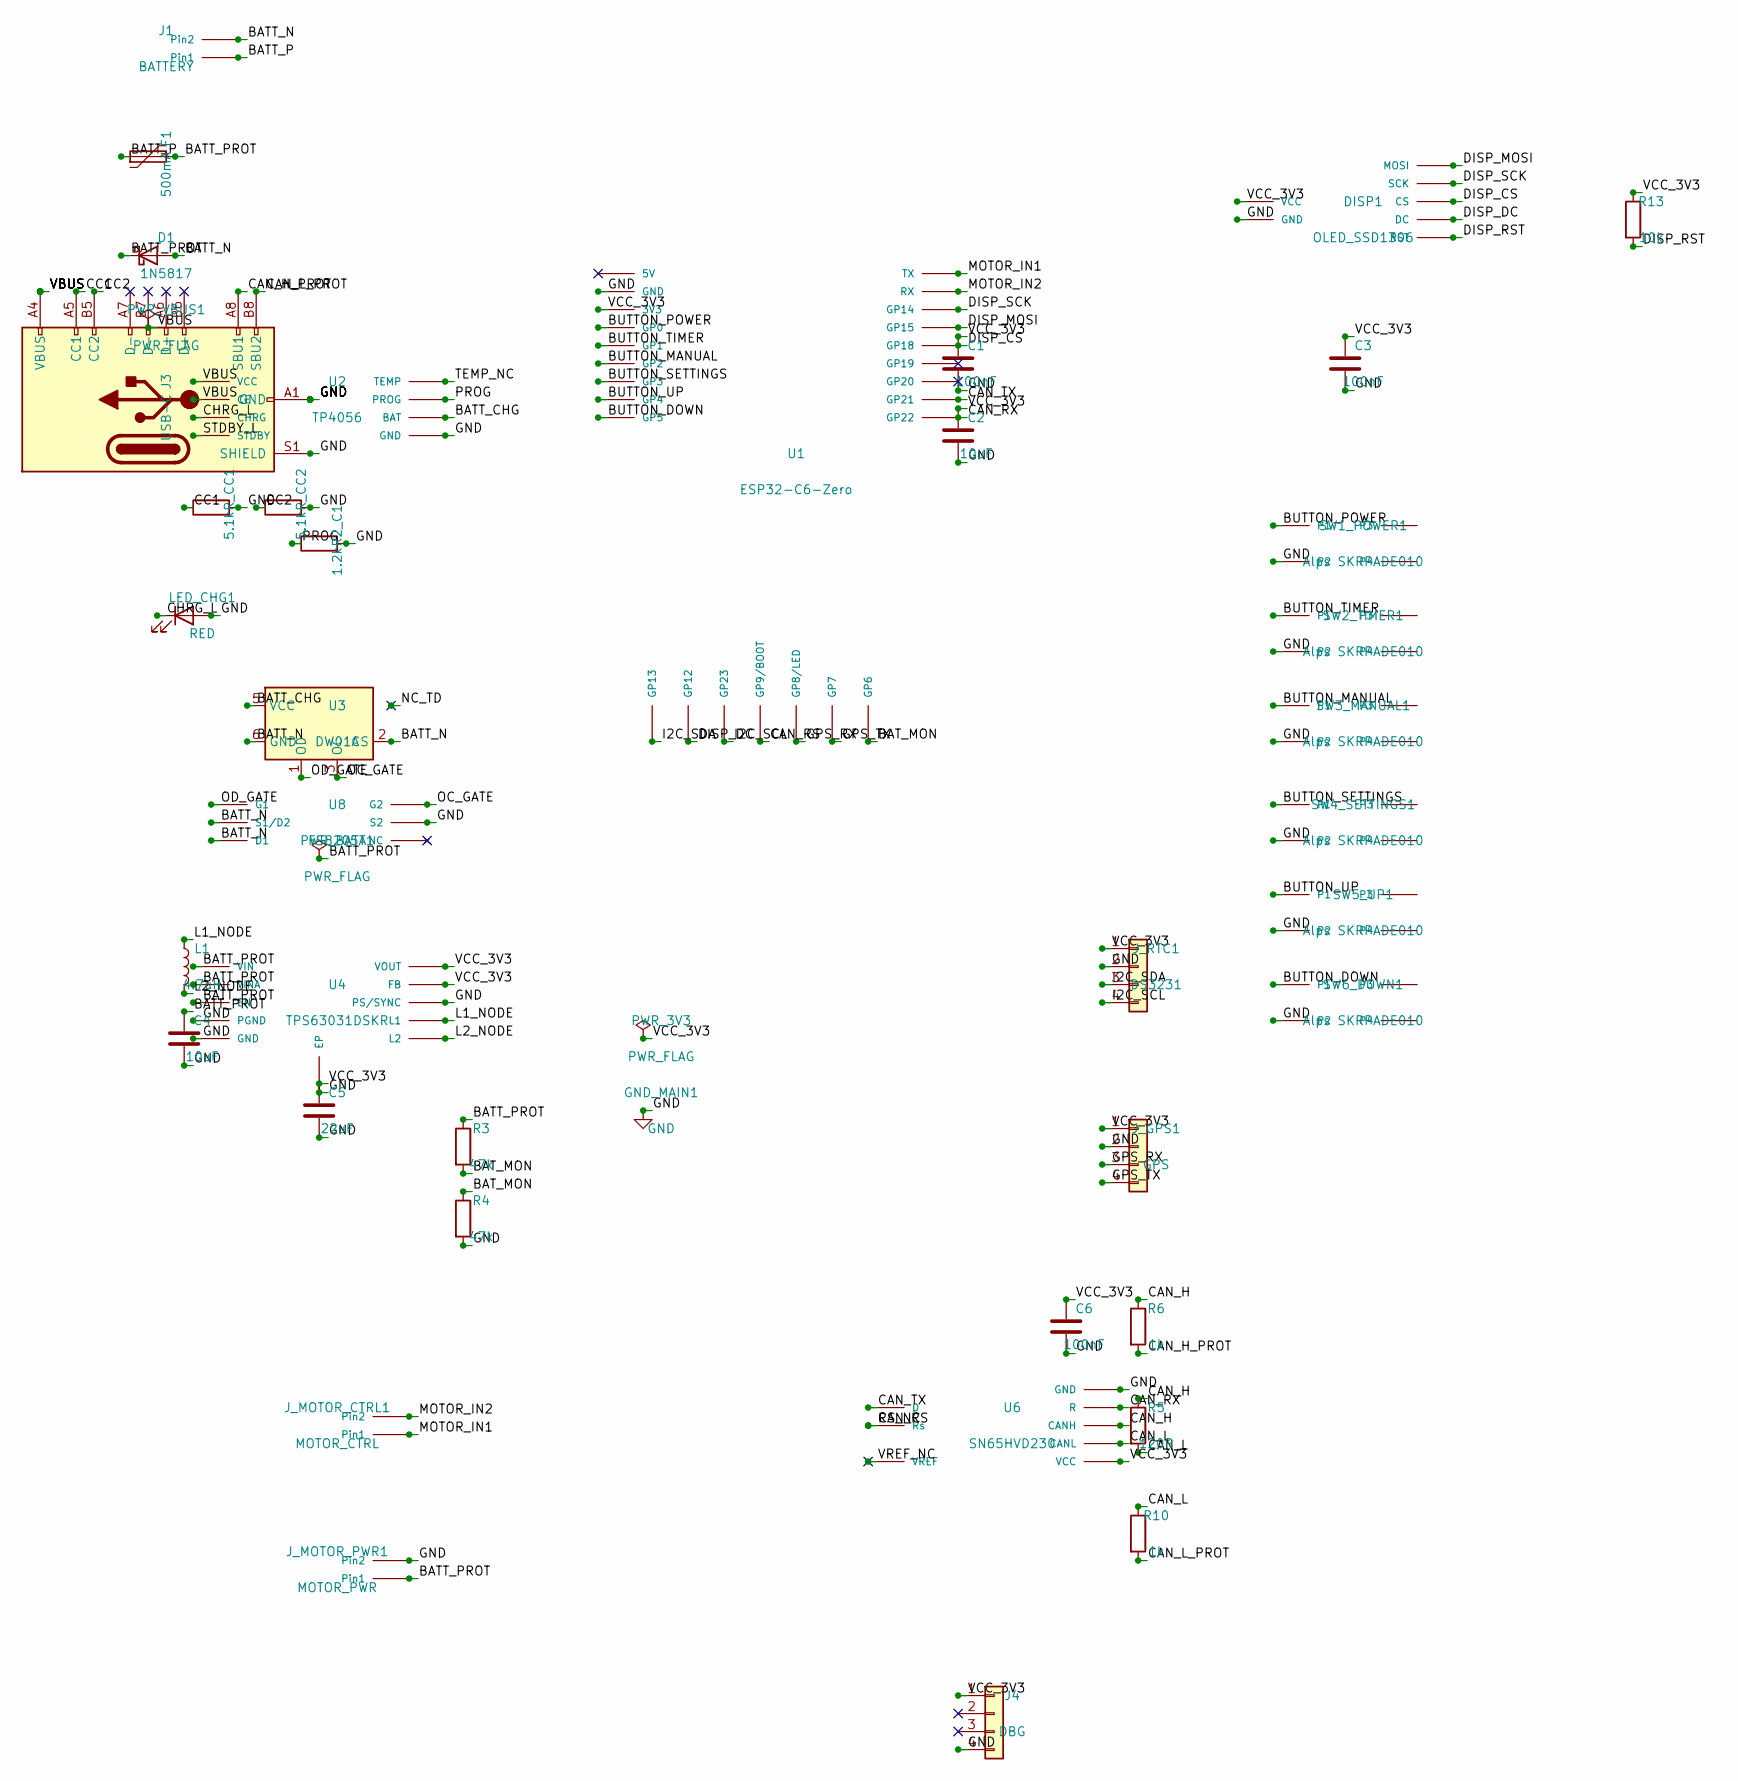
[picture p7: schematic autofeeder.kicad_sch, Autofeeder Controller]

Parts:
C1, C3, C6: 100nF; C_0603_1608Metric
C2, C4: 10uF; C_0805_2012Metric
C5: 22uF; C_0805_2012Metric
D1: 1N5817; D_DO-41_SOD81_P10.16mm_Horizontal
DISP1: OLED_SSD1306; OLED_1.3in_SSD1306_SPI
F1: 500mA; Fuse_1812_4532Metric
GND_MAIN1: GND
J1: BATTERY; JST_XH_B2B-XH-A_1x02_P2.50mm_Vertical
J3: USB-C; USB_C_Receptacle_HRO_TYPE-C-31-M-12
J4: DBG; PinHeader_1x04_P2.54mm_Vertical
J_GPS1: GPS; PinHeader_1x04_P2.54mm_Vertical
J_MOTOR_CTRL1: MOTOR_CTRL; JST_XH_B2B-XH-A_1x02_P2.50mm_Vertical
J_MOTOR_PWR1: MOTOR_PWR; JST_XH_B2B-XH-A_1x02_P2.50mm_Vertical
J_RTC1: DS3231; PinHeader_1x04_P2.54mm_Vertical
L1: 4.7uH; L_0805_2012Metric
LED_CHG1: RED; LED_0603_1608Metric
PWR_3V3: PWR_FLAG
PWR_BATT1: PWR_FLAG
PWR_VBUS1: PWR_FLAG
R2_C1: 1.2k; R_0603_1608Metric
R3, R4: 47k; R_0603_1608Metric
R5: 120R; R_0603_1608Metric
R6, R10: 1k; R_0603_1608Metric
R13: 10k; R_0603_1608Metric
R_CC1, R_CC2: 5.1k; R_0603_1608Metric
SW1_POWER1, SW2_TIMER1, SW3_MANUAL1, SW4_SETTINGS1, SW5_UP1, SW6_DOWN1: Alps SKRPADE010; SW_Push_1P1T_NO_CK_KMR2
U1: ESP32-C6-Zero; ESP32_C6_Zero
U2: TP4056; SOIC-8_3.9x4.9mm_P1.27mm
U3: DW01A; SOT-23-6_Handsoldering
U4: TPS63031DSKR; WSON-10-1EP_2.5x2.5mm_P0.5mm_EP1.2x2mm
U6: SN65HVD230; SOIC-8_3.9x4.9mm_P1.27mm
U8: FS8205A; SOT-23-6_Handsoldering

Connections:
/BATT_CHG: U2.5 (BAT), U3.5 (VCC)
/BATT_N: D1.2 (A), J1.2 (Pin2), U3.2 (CS), U3.6 (GND), U8.2 (S1/D2), U8.3 (D1)
/BATT_P: F1.1, J1.1 (Pin1)
/BATT_PROT: C4.1, D1.1 (K), F1.2, J_MOTOR_PWR1.1 (Pin1), PWR_BATT1.1, R3.1, U4.5 (VIN), U4.6 (EN), U4.8 (VINA)
/BAT_MON: R3.2, R4.1, U1.25 (GP6)
/BUTTON_DOWN: SW6_DOWN1.1, U1.9 (GP5)
/BUTTON_MANUAL: SW3_MANUAL1.1, U1.6 (GP2)
/BUTTON_POWER: SW1_POWER1.1, U1.4 (GP0)
/BUTTON_SETTINGS: SW4_SETTINGS1.1, U1.7 (GP3)
/BUTTON_TIMER: SW2_TIMER1.1, U1.5 (GP1)
/BUTTON_UP: SW5_UP1.1, U1.8 (GP4)
/CAN_H: R5.1, R6.1, U6.7 (CANH)
/CAN_H_PROT: J3.A8 (SBU1), R6.2
/CAN_L: R5.2, R10.1, U6.6 (CANL)
/CAN_L_PROT: J3.B8 (SBU2), R10.2
/CAN_RS: U1.22 (GP9/BOOT), U6.8 (Rs)
/CAN_RX: U1.18 (GP22), U6.4 (R)
/CAN_TX: U1.17 (GP21), U6.1 (D)
/CC1: J3.A5 (CC1), R_CC1.1
/CC2: J3.B5 (CC2), R_CC2.1
/CHRG_L: LED_CHG1.1 (K), U2.1 (CHRG)
/DISP_CS: DISP1.3 (CS), U1.14 (GP18)
/DISP_DC: DISP1.4 (DC), U1.20 (GP12)
/DISP_MOSI: DISP1.7 (MOSI), U1.13 (GP15)
/DISP_RST: DISP1.5 (RST), R13.2
/DISP_SCK: DISP1.6 (SCK), U1.12 (GP14)
/GPS_RX: J_GPS1.3, U1.23 (GP8/LED)
/GPS_TX: J_GPS1.4, U1.24 (GP7)
/I2C_SCL: J_RTC1.4, U1.21 (GP23)
/I2C_SDA: J_RTC1.3, U1.19 (GP13)
/L1_NODE: L1.1, U4.4 (L1)
/L2_NODE: L1.2, U4.2 (L2)
/MOTOR_IN1: J_MOTOR_CTRL1.1 (Pin1), U1.10 (TX)
/MOTOR_IN2: J_MOTOR_CTRL1.2 (Pin2), U1.11 (RX)
/OC_GATE: U3.3 (OC), U8.4 (G2)
/OD_GATE: U3.1 (OD), U8.1 (G1)
/PROG: R2_C1.1, U2.2 (PROG)
/STDBY_L: U2.8 (STDBY)
/TEMP_NC: U2.6 (TEMP)
/VBUS: J3.A4 (VBUS), J3.A9 (VBUS), J3.B4 (VBUS), J3.B9 (VBUS), PWR_VBUS1.1, U2.4 (VCC), U2.7 (CE)
/VCC_3V3: C1.1, C2.1, C3.1, C5.1, C6.1, DISP1.1 (VCC), J4.1, J_GPS1.1, J_RTC1.1, PWR_3V3.1, R13.1, U1.3 (3V3), U4.1 (VOUT), U4.10 (FB), U6.3 (VCC)
/VREF_NC: U6.5 (VREF)
GND: C1.2, C2.2, C3.2, C4.2, C5.2, C6.2, DISP1.2 (GND), GND_MAIN1.1, J3.A1 (GND), J3.A12 (GND), J3.B1 (GND), J3.B12 (GND), J3.S1 (SHIELD), J4.4, J_GPS1.2, J_MOTOR_PWR1.2 (Pin2), J_RTC1.2, LED_CHG1.2 (A), R2_C1.2, R4.2, R_CC1.2, R_CC2.2, SW1_POWER1.2, SW2_TIMER1.2, SW3_MANUAL1.2, SW4_SETTINGS1.2, SW5_UP1.2, SW6_DOWN1.2, U1.2 (GND), U2.3 (GND), U4.3 (PGND), U4.7 (PS/SYNC), U4.9 (GND), U4.11 (EP), U6.2 (GND), U8.5 (S2)

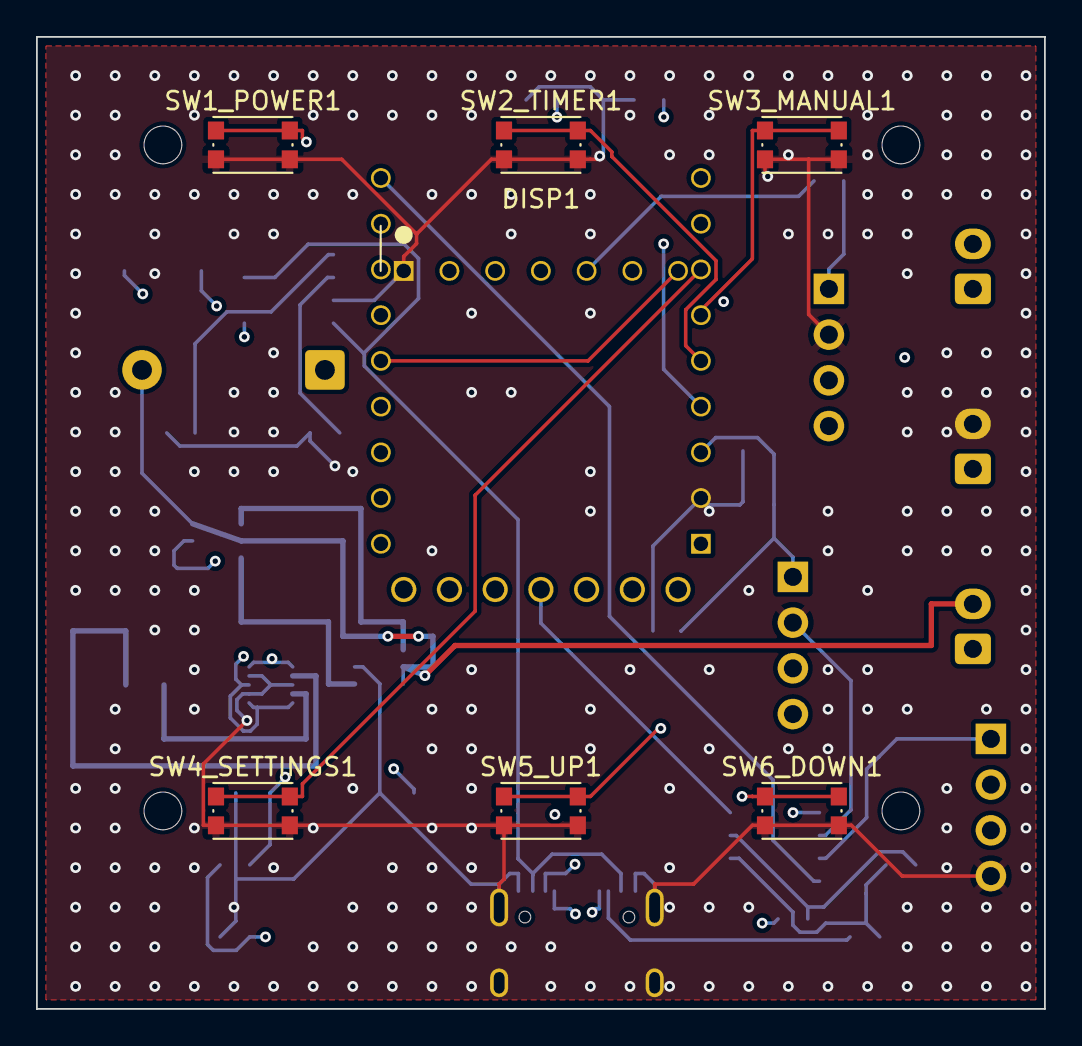
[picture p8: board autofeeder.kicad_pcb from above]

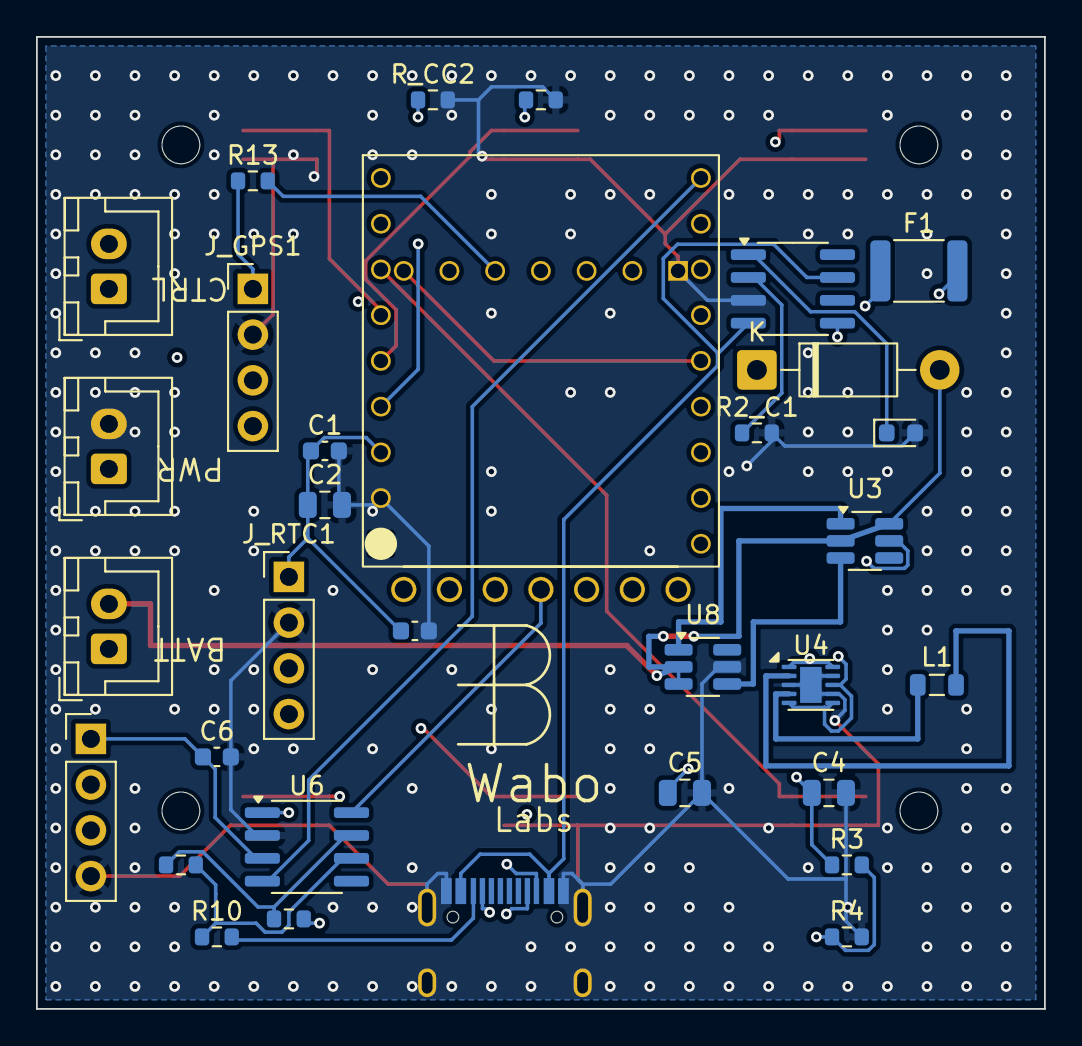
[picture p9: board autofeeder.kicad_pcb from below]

Board: 4 copper layers, 56.0 x 54.0 mm, 44 parts (33 on the bottom side), 40 nets.

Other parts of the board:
H1, H2, H3, H4: MountingHole_2.1mm_NPTH
WABO_LOGO1: Wabo_Labs_Logo

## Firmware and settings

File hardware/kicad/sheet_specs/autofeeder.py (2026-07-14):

"""Autofeeder schematic — single-sheet design for ESP32-C6 chicken feed dispenser.

Usage:
    PYTHONPATH=tools python3 hardware/kicad/sheet_specs/autofeeder.py

Generates hardware/kicad/autofeeder.kicad_sch
"""

from __future__ import annotations

import sys
from pathlib import Path

HERE = Path(__file__).resolve()
REPO_ROOT = HERE.parents[3]
sys.path.insert(0, str(REPO_ROOT / "tools"))

from sch_gen import Sheet, SymbolLibrary


SCH_PATH = REPO_ROOT / "hardware/kicad/autofeeder.kicad_sch"
PROJECT_SYM = str(REPO_ROOT / "hardware/symbols/autofeeder.kicad_sym")

# Footprint constants
FP_R_0603 = "Resistor_SMD:R_0603_1608Metric"
FP_C_0603 = "Capacitor_SMD:C_0603_1608Metric"
FP_C_0805 = "Capacitor_SMD:C_0805_2012Metric"
FP_SOIC8 = "Package_SO:SOIC-8_3.9x4.9mm_P1.27mm"
FP_JST_XH = "Connector_JST:JST_XH_B2B-XH-A_1x02_P2.50mm_Vertical"
FP_USB_C = "Connector_USB:USB_C_Receptacle_HRO_TYPE-C-31-M-12"
FP_PIN_1x4 = "Connector_PinHeader_2.54mm:PinHeader_1x04_P2.54mm_Vertical"
FP_OLED = "autofeeder:OLED_1.3in_SSD1306_SPI"
# Compact ~4x4 SMD tactile (CK KMR2 series), matching the original board's small buttons.
# Front-only pads keep the dense back side clear; narrow pads clear the corner mounting
# holes at their measured positions.
FP_SW_TACT = "Button_Switch_SMD:SW_Push_1P1T_NO_CK_KMR2"
FP_ESP = "autofeeder:ESP32_C6_Zero"    # 2.54mm TH socket for Waveshare ESP32-C6-Zero
FP_SOT23_6_HS = "Package_TO_SOT_SMD:SOT-23-6_Handsoldering"
FP_L_0805 = "Inductor_SMD:L_0805_2012Metric"
FP_WSON10_TPS63031 = "Package_SON:WSON-10-1EP_2.5x2.5mm_P0.5mm_EP1.2x2mm"


def build() -> Sheet:
    lib = SymbolLibrary(project_lib=PROJECT_SYM)
    s = Sheet(
        name="autofeeder",
        uuid="00000000-0000-0000-0000-000000000000",
        page=1,
        paper="A4",
        title="Autofeeder Controller",
        rev="1.0",
        date="2026-06-02",
        company="CoopTech",
        lib=lib,
        project_name="autofeedermod",
    )

    def label_pins(comp, labels: dict[str, str]):
        for pin_num, net_name in labels.items():
            try:
                pos = comp.pin_xy(pin_num)
                label_at(net_name, pos)
            except KeyError:
                pass

    def label_at(name: str, pos: tuple[float, float]):
        stub = (pos[0] + 1.27, pos[1])
        s.wire(pos, stub)
        s.local_label(name, stub)
        s.junction(pos)

    # ===== POWER SECTION =====

    # J1: Battery JST XH
    j1 = s.add("J1", "autofeeder:JST_XH_2P", "BATTERY", at=(30, 15), footprint=FP_JST_XH)
    label_pins(j1, {"1": "BATT_P", "2": "BATT_N"})

    # F1: PTC fuse
    f1 = s.add("F1", "Device:Polyfuse", "500mA", at=(30, 30), rotation=90,
               footprint="Fuse:Fuse_1812_4532Metric")
    label_pins(f1, {"1": "BATT_P", "2": "BATT_PROT"})

    # D1: Schottky protection
    d1 = s.add("D1", "Device:D_Schottky", "1N5817", at=(30, 45),
               footprint="Diode_THT:D_DO-41_SOD81_P10.16mm_Horizontal")
    label_pins(d1, {"1": "BATT_PROT", "2": "BATT_N"})

    # J3: USB-C
    j3 = s.add("J3", "Connector:USB_C_Receptacle_USB2.0_16P",
               "USB-C", at=(30, 65), rotation=90, footprint=FP_USB_C)
    # USB-C VBUS: A4, A9, B4, B9
    for vbus_pin in ("A4", "A9", "B4", "B9"):
        label_at("VBUS", j3.pin_xy(vbus_pin))
    # USB-C GND: A1, A12, B1, B12
    for gnd_pin in ("A1", "A12", "B1", "B12"):
        label_at("GND", j3.pin_xy(gnd_pin))
    # USB-C SHIELD → GND (reduces EMI, reference for ESD discharge path)
    label_at("GND", j3.pin_xy("S1"))
    # USB-C CC pins: 5.1k to GND
    cc1 = s.add("R_CC1", "Device:R", "5.1k", at=(40, 80), rotation=90, footprint=FP_R_0603)
    cc2 = s.add("R_CC2", "Device:R", "5.1k", at=(50, 80), rotation=90, footprint=FP_R_0603)
    label_pins(cc1, {"1": "CC1", "2": "GND"})
    label_pins(cc2, {"1": "CC2", "2": "GND"})
    label_at("CC1", j3.pin_xy("A5"))
    label_at("CC2", j3.pin_xy("B5"))
    # D+/D- no connect
    s.no_connect(j3.pin_xy("A6"))
    s.no_connect(j3.pin_xy("A7"))
    s.no_connect(j3.pin_xy("B6"))
    s.no_connect(j3.pin_xy("B7"))
    # SBU1/2 → CAN_H_PROT/L_PROT via series resistors (handled below)
    # (no direct labels here — the CAN series protection resistors R6/R10
    #  connect via CAN_H_PROT / CAN_L_PROT labels at the USB-C side)

    # U2: TP4056 charger
    u2 = s.add("U2", "autofeeder:TP4056", "TP4056", at=(55, 65), footprint=FP_SOIC8)
    label_pins(u2, {"4": "VBUS", "3": "GND", "5": "BATT_CHG",
                    "2": "PROG", "1": "CHRG_L", "7": "VBUS", "6": "TEMP_NC", "8": "STDBY_L"})

    # R2: PROG resistor (1.2k for 1A charge)
    r2 = s.add("R2_C", "Device:R", "1.2k", at=(55, 85), rotation=90, footprint=FP_R_0603)
    label_pins(r2, {"1": "PROG", "2": "GND"})

    # LED2: Charge indicator (RED, CHRG = active low)
    led2 = s.add("LED_CHG", "Device:LED", "RED", at=(35, 95), footprint="LED_SMD:LED_0603_1608Metric")
    label_pins(led2, {"1": "CHRG_L", "2": "GND"})
    # Note: CHRG is open-drain, so LED cathode goes to GND, anode to CHRG
    # Meaning: LED illuminates when CHRG pulls low (charging)

    # U3: DW01A battery protection IC (SOT-23-6, hand-solderable)
    u3 = s.add("U3", "Battery_Management:DW01A", "DW01A", at=(55, 110),
               footprint=FP_SOT23_6_HS)
    label_pins(u3, {"5": "BATT_CHG", "6": "BATT_N", "1": "OD_GATE",
                    "3": "OC_GATE", "2": "BATT_N", "4": "NC_TD"})
    s.no_connect(u3.pin_xy("4"))

    # U8: FS8205A dual NMOS (SOT-23-6) — charge/discharge protection FETs driven by DW01A
    u8 = s.add("U8", "autofeeder:FS8205A", "FS8205A", at=(55, 125),
               footprint=FP_SOT23_6_HS)
    label_pins(u8, {"1": "OD_GATE", "4": "OC_GATE",
                    "2": "BATT_N", "3": "BATT_N", "5": "GND"})
    s.no_connect(u8.pin_xy("6"))

    # U4: TPS63031DSKR buck-boost (WSON-10, fixed 3.3V output)
    # Fixed 3.3V output — no feedback resistors needed. Pinout per DSK package:
    # 1=VOUT, 2=L2, 3=PGND, 4=L1, 5=VIN, 6=EN, 7=PS/SYNC, 8=VINA, 9=GND, 10=FB, 11=EP
    u4 = s.add("U4", "autofeeder:TPS63031DSKR", "TPS63031DSKR", at=(55, 150), footprint=FP_WSON10_TPS63031)
    label_pins(u4, {"5": "BATT_PROT",   # VIN
                    "8": "BATT_PROT",   # VINA
                    "6": "BATT_PROT",   # EN (tie to input to always enable)
                    "3": "GND",         # PGND
                    "9": "GND",         # GND
                    "7": "GND",         # PS/SYNC (GND=enable power-save mode)
                    "1": "VCC_3V3",     # VOUT
                    "10": "VCC_3V3",    # FB (tie to VOUT for fixed 3.3V)
                    "4": "L1_NODE",     # L1
                    "2": "L2_NODE",     # L2
                    "11": "GND"})       # EP (exposed thermal pad, per datasheet PowerPAD)

    # L1: 4.7uH inductor for TPS63031 L1-L2 (SW node to VOUT)
    l1 = s.add("L1", "Device:L", "4.7uH", at=(35, 145), footprint=FP_L_0805)
    label_pins(l1, {"1": "L1_NODE", "2": "L2_NODE"})

    # C4, C5: TPS63031 input/output caps
    c4 = s.add("C4", "Device:C", "10uF", at=(35, 155), footprint=FP_C_0805)
    label_pins(c4, {"1": "BATT_PROT", "2": "GND"})
    c5 = s.add("C5", "Device:C", "22uF", at=(55, 165), footprint=FP_C_0805)
    label_pins(c5, {"1": "VCC_3V3", "2": "GND"})

    # R3, R4: Battery voltage divider (BAT_MON)
    r3 = s.add("R3", "Device:R", "47k", at=(75, 170), footprint=FP_R_0603)
    r4 = s.add("R4", "Device:R", "47k", at=(75, 180), footprint=FP_R_0603)
    label_pins(r3, {"1": "BATT_PROT", "2": "BAT_MON"})
    label_pins(r4, {"1": "BAT_MON", "2": "GND"})

    # ===== MCU SECTION =====

    # U1: Waveshare ESP32-C6-Zero (socketed via 2x9 2.54mm pin socket headers)
    # Powered via 3V3 pin directly from RT6150A — Zero's internal LDO is bypassed.
    # Zero's onboard USB-C handles flashing (tucked inside enclosure; open case to access).
    # Pinout confirmed from official Waveshare diagram:
    #   Left  (1-9) : 5V  GND  3V3  GP0-GP5
    #   Right (10-18): TX  RX  GP14 GP15 GP18 GP19 GP20 GP21 GP22
    #   Bottom(19-25): GP13 GP12 GP23 GP9/BOOT GP8/LED GP7 GP6
    u1 = s.add("U1", "autofeeder:ESP32_C6_Zero", "ESP32-C6-Zero",
               at=(120, 75), footprint=FP_ESP)
    # Power
    label_pins(u1, {"3": "VCC_3V3", "2": "GND"})
    s.no_connect(u1.pin_xy("1"))      # 5V: unused — main board USB-C powers TP4056
    # Buttons: GP0-GP5 on left rail (all ADC-capable, 6 buttons)
    label_pins(u1, {"4": "BUTTON_POWER", "5": "BUTTON_TIMER",
                    "6": "BUTTON_MANUAL", "7": "BUTTON_SETTINGS",
                    "8": "BUTTON_UP", "9": "BUTTON_DOWN"})
    # Motor control on TX/RX pads (right rail top 2) — repurposed from UART programming.
    # Programming is done via the Zero's own USB-C (tucked inside enclosure) or boot-ROM mode.
    label_pins(u1, {"10": "MOTOR_IN1", "11": "MOTOR_IN2"})
    # Display SPI: GP14=SCK, GP15=MOSI, GP18=CS
    # DISP_DC moved to bottom pad GP12 to resolve pin conflict with MOTOR_IN1 (both on GPIO19)
    label_pins(u1, {"12": "DISP_SCK", "13": "DISP_MOSI",
                    "14": "DISP_CS"})
    # GPIO19 (pad 15) and GPIO20 (pad 16) are NC — conflicts with MOTOR pins resolved
    s.no_connect(u1.pin_xy("15"))
    s.no_connect(u1.pin_xy("16"))
    # CAN bus: GP21=TX, GP22=RX
    label_pins(u1, {"17": "CAN_TX", "18": "CAN_RX"})
    # Bottom edge pads (19-25) — accessed via pogo pins soldered into through-holes.
    # These contact the Zero module's bottom castellated pads.
    # Pad 20 (GP12): DISP_DC (moved from conflicted GPIO19)
    # Pad 25 (GP6):  BAT_MON (moved from conflicted GPIO20, ADC-capable)
    # Pad 19 (GP13): I2C_SDA (DS3231 RTC)
    # Pad 21 (GP23): I2C_SCL (DS3231 RTC)
    # Pad 24 (GP7):  GPS_TX (UART TX to GPS module)
    # Pad 23 (GP8):  GPS_RX (UART RX from GPS module, strapping — input only)
    # Pad 22 (GP9):  NC (BOOT strapping, avoid)
    label_pins(u1, {"20": "DISP_DC", "25": "BAT_MON",
                    "19": "I2C_SDA", "21": "I2C_SCL",
                    "24": "GPS_TX", "23": "GPS_RX"})
    # GP9/BOOT — strapping, used to drive CAN_RS (SN65HVD230 standby)
    # HIGH during sleep = CAN standby mode (~1µA); LOW during active = CAN high-speed
    label_pins(u1, {"22": "CAN_RS"})

    # C1, C2: ESP32 decoupling
    c1 = s.add("C1", "Device:C", "100nF", at=(145, 60), footprint=FP_C_0603)
    label_pins(c1, {"1": "VCC_3V3", "2": "GND"})
    c2 = s.add("C2", "Device:C", "10uF", at=(145, 70), footprint=FP_C_0805)
    label_pins(c2, {"1": "VCC_3V3", "2": "GND"})

    # R9: EN pull-up removed — EN is internal on the ESP32-C6-Zero and not exposed on the socket.

    # ===== MOTOR SECTION =====
    # MX1508 dual H-bridge breakout board, connected via 2× JST XH 2-pin cables
    # Motor output connects directly from MX1508 to the motor — not on main PCB.

    # J_MOTOR_CTRL: MX1508 logic inputs from ESP32
    j_mtr_ctrl = s.add("J_MOTOR_CTRL", "autofeeder:JST_XH_2P", "MOTOR_CTRL", at=(55, 210), footprint=FP_JST_XH)
    label_pins(j_mtr_ctrl, {"1": "MOTOR_IN1", "2": "MOTOR_IN2"})

    # J_MOTOR_PWR: MX1508 power supply (battery + ground)
    j_mtr_pwr = s.add("J_MOTOR_PWR", "autofeeder:JST_XH_2P", "MOTOR_PWR", at=(55, 230), footprint=FP_JST_XH)
    label_pins(j_mtr_pwr, {"1": "BATT_PROT", "2": "GND"})

    # ===== CAN SECTION =====

    # U6: SN65HVD230 CAN transceiver
    u6 = s.add("U6", "autofeeder:SN65HVD230", "SN65HVD230", at=(150, 210), footprint=FP_SOIC8)
    label_pins(u6, {"1": "CAN_TX", "4": "CAN_RX", "8": "RS_NC",
                    "7": "CAN_H", "6": "CAN_L",
                    "5": "VREF_NC", "3": "VCC_3V3", "2": "GND"})
    s.no_connect(u6.pin_xy("5"))
    # RS pin (8) driven by GP9 for standby mode during sleep
    label_pins(u6, {"8": "CAN_RS"})

    # R5: CAN termination (120R, selectable via solder jumper)
    r5 = s.add("R5", "Device:R", "120R", at=(170, 210), footprint=FP_R_0603)
    label_pins(r5, {"1": "CAN_H", "2": "CAN_L"})

    # R6, R10: CAN series protection
    r6 = s.add("R6", "Device:R", "1k", at=(170, 195), footprint=FP_R_0603)
    r10 = s.add("R10", "Device:R", "1k", at=(170, 225), footprint=FP_R_0603)
    label_pins(r6, {"1": "CAN_H", "2": "CAN_H_PROT"})
    label_pins(r10, {"1": "CAN_L", "2": "CAN_L_PROT"})
    label_at("CAN_H_PROT", j3.pin_xy("A8"))
    label_at("CAN_L_PROT", j3.pin_xy("B8"))

    # C6: CAN decoupling
    c6 = s.add("C6", "Device:C", "100nF", at=(160, 195), footprint=FP_C_0603)
    label_pins(c6, {"1": "VCC_3V3", "2": "GND"})

    # ===== DISPLAY SECTION =====

    # DISP1: SSD1306 OLED
    disp1 = s.add("DISP1", "autofeeder:OLED_SSD1306_SPI", "OLED_SSD1306", at=(200, 40), footprint=FP_OLED)
    label_pins(disp1, {"1": "VCC_3V3", "2": "GND",
                       "3": "DISP_CS", "4": "DISP_DC",
                       "5": "DISP_RST", "6": "DISP_SCK", "7": "DISP_MOSI"})

    # C3: Display decoupling
    c3 = s.add("C3", "Device:C", "100nF", at=(200, 60), footprint=FP_C_0603)
    label_pins(c3, {"1": "VCC_3V3", "2": "GND"})

    # ===== BUTTONS =====

    btn_config = [
        ("SW1_POWER", "BUTTON_POWER", (200, 85)),
        ("SW2_TIMER", "BUTTON_TIMER", (200, 98)),
        ("SW3_MANUAL", "BUTTON_MANUAL", (200, 111)),
        ("SW4_SETTINGS", "BUTTON_SETTINGS", (200, 124)),
        ("SW5_UP", "BUTTON_UP", (200, 137)),
        ("SW6_DOWN", "BUTTON_DOWN", (200, 150)),
    ]
    for ref, net, pos in btn_config:
        sw = s.add(ref, "autofeeder:SW_ALPS_SKRPADE010", "Alps SKRPADE010",
                   at=pos, footprint=FP_SW_TACT)
        # Pins 1-2 are one switch, 3-4 are the other (4-pin tactile switch)
        # Connect P1 to the GPIO, P2 to GND (or P3/P4 respectively)
        label_at(net, sw.pin_xy("1"))
        label_at("GND", sw.pin_xy("2"))

    # ===== PROGRAMMING HEADER =====

    # J4: debug/power header (UART pads repurposed for motor; Zero's USB-C handles flashing)
    j4 = s.add("J4", "Connector_Generic:Conn_01x04", "DBG", at=(150, 250), footprint=FP_PIN_1x4)
    label_pins(j4, {"1": "VCC_3V3", "4": "GND"})
    s.no_connect(j4.pin_xy("2"))
    s.no_connect(j4.pin_xy("3"))

    # ===== RTC SECTION (DS3231 module) =====

    # J_RTC: 4-pin header for DS3231 module (ZS-042 or equivalent)
    # Pinout: VCC, GND, SDA, SCL. Module has onboard pull-ups and CR2032 holder.
    j_rtc = s.add("J_RTC", "Connector_Generic:Conn_01x04", "DS3231", at=(170, 145),
                  footprint=FP_PIN_1x4)
    label_pins(j_rtc, {"1": "VCC_3V3", "2": "GND", "3": "I2C_SDA", "4": "I2C_SCL"})

    # ===== GPS SECTION =====

    # J_GPS: 4-pin header for NEO-6M/NEO-8M GPS module
    # Pinout: VCC, GND, GPS_RX (module TX→ESP), GPS_TX (ESP→module RX)
    j_gps = s.add("J_GPS", "Connector_Generic:Conn_01x04", "GPS", at=(170, 170),
                  footprint=FP_PIN_1x4)
    label_pins(j_gps, {"1": "VCC_3V3", "2": "GND", "3": "GPS_RX", "4": "GPS_TX"})

    # ===== DISPLAY PULL-UPS =====

    # R13: DISP_RST pull-up — SSD1306 RST pin held high; no GPIO needed for hardware reset
    r13 = s.add("R13", "Device:R", "10k", at=(240, 40), footprint=FP_R_0603)
    label_pins(r13, {"1": "VCC_3V3", "2": "DISP_RST"})

    # STATUS LED: replaced by the WS2812B RGB LED built into the ESP32-C6-Zero (on IO8/pad 12).
    # No discrete LED or current-limit resistor needed on the main board.

    # ===== POWER SYMBOLS =====

    pwr_vbus = s.add("PWR_VBUS", "power:PWR_FLAG", "PWR_FLAG", at=(30, 55))
    label_at("VBUS", pwr_vbus.pin_xy("1"))

    pwr_batt = s.add("PWR_BATT", "power:PWR_FLAG", "PWR_FLAG", at=(55, 130))
    label_at("BATT_PROT", pwr_batt.pin_xy("1"))

    pwr_3v3 = s.add("PWR_3V3", "power:PWR_FLAG", "PWR_FLAG", at=(100, 155))
    label_at("VCC_3V3", pwr_3v3.pin_xy("1"))

    gnd_main = s.add("GND_MAIN", "power:GND", "GND", at=(100, 165))
    label_at("GND", gnd_main.pin_xy("1"))

    return s


def main() -> None:
    s = build()
    SCH_PATH.parent.mkdir(parents=True, exist_ok=True)
    s.check_paren_balance()
    s.write(SCH_PATH)
    print(f"wrote {SCH_PATH}")
    print(f"  components: {len(s.components)}  local labels: {len(s.local_labels)}")


if __name__ == "__main__":
    main()

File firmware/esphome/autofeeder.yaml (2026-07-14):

substitutions:
  name: autofeeder
  friendly_name: "Chicken Feed Dispenser"

esphome:
  name: ${name}
  friendly_name: ${friendly_name}
  platformio_options:
    board_build.flash_mode: dio
  includes:
    - custom_components/display_sleep.h
  on_boot:
    priority: -100
    then:
      - script.execute: idle_timeout

custom_component:
  - id: display_sleep
    lambda: |-
      return {new DisplaySleepComponent(12, 18, 14, 15)};

deep_sleep:
  id: sleep_control
  wakeup_pin:
    number: GPIO0
    allow_during_deep_sleep: true

output:
  - platform: gpio
    pin: GPIO9
    id: can_rs_out
    restore_mode: ALWAYS_OFF

esp32:
  board: esp32-c6-devkitc-1
  framework:
    type: esp-idf
    version: recommended

wifi:
  ssid: !secret wifi_ssid
  password: !secret wifi_password
  enable_on_boot: true

# ===== I2C BUS (DS3231 RTC) =====
i2c:
  sda: 13
  scl: 23
  scan: false
  frequency: 100kHz

# ===== TIME SOURCES =====
time:
  - platform: ds1307
    id: rtc_time
    on_time:
      - seconds: 0
        minutes: /1
        then:
          - lambda: |-
              static int last_checked_minute = -1;
              auto now = id(rtc_time).now();
              if (!now.is_valid()) return;
              int current_min = now.minute;
              if (current_min == last_checked_minute) return;
              last_checked_minute = current_min;
              for (int slot = 0; slot < 4; slot++) {
                int h, m, d; bool en;
                switch (slot) {
                  case 0: h = id(sched0_hour); m = id(sched0_min); d = id(sched0_dur); en = id(sched0_enabled); break;
                  case 1: h = id(sched1_hour); m = id(sched1_min); d = id(sched1_dur); en = id(sched1_enabled); break;
                  case 2: h = id(sched2_hour); m = id(sched2_min); d = id(sched2_dur); en = id(sched2_enabled); break;
                  case 3: h = id(sched3_hour); m = id(sched3_min); d = id(sched3_dur); en = id(sched3_enabled); break;
                }
                if (en && now.hour == h && now.minute == m && d > 0) {
                  id(feed_active) = true;
                  id(feed_duration) = d;
                  id(feed_remaining) = d;
                }
              }
  - platform: sntp
    id: sntp_time

# ===== GPS (NEO-6M/NEO-8M — Optional) =====
uart:
  id: uart_bus
  tx_pin: 7
  rx_pin: 8
  baud_rate: 9600

gps:
  id: gps_device
  uart_id: uart_bus

# ===== DISPLAY (SSD1306 128x64 SPI) =====
spi:
  clk_pin: 14
  mosi_pin: 15

font:
  - file: "gfonts://Roboto"
    id: font_small
    size: 10
  - file: "gfonts://Roboto"
    id: font_medium
    size: 12
  - file: "gfonts://Roboto"
    id: font_large
    size: 16

display:
  - platform: ssd1306_spi
    model: "SSD1306 128x64"
    cs_pin: 18
    dc_pin: 12
    rotation: 0
    lambda: |-
      auto now = id(rtc_time).now();
      int menu = id(menu_state);
      it.clear();

      if (id(feed_active)) {
        it.printf(0, 0, id(font_large), "FEEDING...");
        it.printf(0, 24, id(font_medium), "%ds left", id(feed_remaining));
        return;
      }

      switch (menu) {

        case 0:
          if (now.is_valid()) {
            it.strftime(0, 0, id(font_large), "%H:%M", now);
            it.strftime(0, 18, id(font_small), "%a %b %d", now);
          } else {
            it.printf(0, 0, id(font_large), "--:--");
            it.printf(0, 18, id(font_small), "No RTC time");
          }
          it.printf(0, 34, id(font_small), "Bat: %.2fV", id(battery_voltage).state);
          break;

        case 1:
          if (id(feed_active)) break;
          it.printf(0, 0, id(font_medium), "MANUAL FEED");
          it.printf(0, 18, id(font_small), "Duration: %ds", id(manual_duration));
          it.printf(0, 34, id(font_small), "UP/DN: adjust");
          it.printf(0, 50, id(font_small), "MANUAL: start");
          break;

        case 2:
          it.printf(0, 0, id(font_medium), "Schedules");
          for (int i = 0; i < 4; i++) {
            int h, m, d; bool en;
            switch (i) {
              case 0: h = id(sched0_hour); m = id(sched0_min); d = id(sched0_dur); en = id(sched0_enabled); break;
              case 1: h = id(sched1_hour); m = id(sched1_min); d = id(sched1_dur); en = id(sched1_enabled); break;
              case 2: h = id(sched2_hour); m = id(sched2_min); d = id(sched2_dur); en = id(sched2_enabled); break;
              case 3: h = id(sched3_hour); m = id(sched3_min); d = id(sched3_dur); en = id(sched3_enabled); break;
            }
            int y = 14 + i * 12;
            if (id(sched_cursor) == i) it.print(0, y, id(font_small), ">");
            it.printf(8, y, id(font_small), "S%d %s %02d:%02d %ds",
                      i + 1, en ? "ON " : "OFF", h, m, d);
          }
          break;
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

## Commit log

2026-06-02 Initial autofeeder controller board design
    ESP32-C6 based PCB replacement for chicken feed dispenser.
    - KiCad project with full schematic (USB-C + 18650 battery + CAN)
    - Symbol library for ESP32-C6, TP4056, TPS63802, DRV8871, SN65HVD230
    - ESPHome firmware skeleton with Matter support
    - CERN-OHL-W-2.0 open hardware license
    [autofeedermod.kicad_pcb, autofeedermod.kicad_sch]
2026-06-02 Add Python PCB generation pipeline for autofeeder controller
    - Python S-expression library (tools/sch_gen/) for KiCad file generation
    - Declarative Sheet builder with component placement, wire stubs, net labels
    - Symbol library for custom parts (JST, OLED, Alps switch, ICs)
    - Full schematic generator: 41 components, power/MCU/motor/CAN/display
    - Generated KiCad 9 schematic with board outline (56x54mm)
    - PCB generation pipeline script (headless placement + routing)
    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
    [autofeeder.kicad_pcb, autofeeder.kicad_sch]
2026-06-03 Snapshot current design (ESP32-C6-Zero, RT6150A buck-boost, FS8205A protection)
    - Switch from ESP32-C6-WROOM module to Waveshare ESP32-C6-Zero (socketed)
    - Replace TPS63802 (QFN) with RT6150A (SOT-23-6, hand-solderable)
    - Split DW01A+FS8205A into separate U3/U8 symbols (SOT-23-6)
    - Add gerber/drill/CPL fabrication output
    - Add mounting holes and OLED SPI display footprint
    - Generate schematic + PCB from Python pipeline scripts
    [autofeeder-B_Cu.gbl, autofeeder-B_Mask.gbs, autofeeder-B_Paste.gbp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]
2026-06-04 Add RTC, GPS, pogo pin support and standalone firmware
    - Fix GPIO19/GPIO20 pin conflicts: move DISP_DC to GP12 (bottom pad),
    BAT_MON to GP6 (bottom pad)
    - Add J_RTC header: DS3231 RTC module on I2C (GP13/GP23)
    - Add J_GPS header: NEO-6M/8M GPS module on UART (GP7/GP8)
    - Enlarge bottom edge pads 19-25 to 1.0mm drill for 0.9mm pogo pins
    - Rewrite ESPHome firmware: DS3231 RTC time, GPS, 6-page display menu,
    4 persistent schedule slots, button-driven local control
    - Update pinout, BOM, and PCB placement for all new components
    [autofeeder-B_Cu.gbl, autofeeder-B_Mask.gbs, autofeeder-B_Paste.gbp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]
2026-06-05 Add standalone firmware with RTC, GPS, OLED UI, and menu system
    - ESPHome firmware (autofeeder.yaml): RTC timekeeping with DS1307, SNTP+GPS
    fallback, SSD1306 display with clock/manual feed/schedules/GPS/Settings menu,
    6 GPIO buttons, DRV8871 motor control, battery monitoring, CAN bus
    - GPS time sync: 30s interval checks TinyGPSPlus, sets system time via
    settimeofday, persists to DS1307 via write_time()
    - Hardware: J_RTC at (28,36) back side under OLED, J_GPS at (44,14) top-right,
    U4 TPS63031 WSON-10 footprint fix, bottom pads 19-25 enlarged to 1.0mm for
    0.9mm pogo pins
    - Fabrication outputs regenerated (Gerbers, BOM, CPL)
    - Docs: pinout.md, bom.md updated for new headers and module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
    [autofeeder-B_Cu.gbl, autofeeder-B_Mask.gbs, autofeeder-B_Paste.gbp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]
2026-07-14 Fix BATT_N unconnected net, migrate to 4-layer PCB, refresh fab outputs
    - Add _pre_route_batt_n() to route BATT_N net (DW01A ↔ FS8205A protection ICs)
    via B.Cu segments + F.Cu through-via, eliminating the last unconnected net
    - Update README power topology to include DW01A/FS8205A protection
    - Update docs/bom.md: 2→4 layer count, remove stale bodge wire instructions,
    update DRC status to reflect 0 unconnected items
    - Regenerate all fab outputs (gerbers, drill, BOM, CPL, DRC) for 4-layer board
    - Add inner copper layers (In1.Cu, In2.Cu) to gerber set
    - Add Wabo Labs logo footprint, display_sleep custom component
    - Add MX1508 reference datasheets
    [autofeeder-B_Cu.gbl, autofeeder-B_Mask.gbs, autofeeder-B_Paste.gbp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]
2026-07-14 Fix three real shorts in BATT_N pre-routes (battery short + gate crossing)
    Commit 04d4fbc shipped 3 DRC error-level violations mislabeled as "marginal
    clearance". They were real shorts, all in _pre_route_batt_n():
    1. BATT_N F.Cu track grazed J1 pad 1 (BATT_P) -> dead short across the battery.
    2. OD_GATE (x=20.35 vert) and BATT_N (y=33.3 horiz) crossed on B.Cu at
    (20.35,33.3) -> gate/BATT_N short.
    3. Solder-mask bridge at the same spot as #1.
    Fixes:
    - F.Cu J1 exit rerouted left at y=31.5 then down at x=49.69 (left of pad 1's
    x=51 edge), so it never approaches BATT_P.
    - B.Cu U3->U8-2 chain keeps the high y=33.3 path but hops OVER the OD_GATE
    vertical on F.Cu (x19.5->21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
    [autofeeder-B_Cu.gbl, autofeeder-B_Mask.gbs, autofeeder-B_Paste.gbp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]
2026-07-14 Set footprint Value + full FPID in populate() (schematic parity)
    populate() only called SetReference(), so every footprint kept the library's
    default Value (the footprint name, e.g. C1 showed "C_0603_1608Metric" instead of
    "100nF") and a bare FPID without its library nickname. That made all 39 components
    fail schematic-parity on the value and footprint fields (78 mismatches) and made
    the PCB unreadable, even though the copper/nets were correct.
    Now carry the schematic value (_value_name from the netlist) via SetValue() and
    the full lib:name FPID via SetFPIDAsString(). Schematic parity drops 95 -> 17;
    the remaining 17 are out of scope (12 = 4-pin switch symbol vs 2-pad KMR2
    footprint, button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
    [autofeeder-B_Cu.gbl, autofeeder-B_Mask.gbs, autofeeder-B_Paste.gbp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]
2026-07-14 Add fab & parts-acquisition plan + SMT-only BOM/CPL, refresh gerber zip
    - fabrication/FAB-AND-PARTS.md: step-by-step plan (bare-board specs, double-sided
    SMT assembly, customer-supplied modules, hand-solder connectors, bring-up).
    - autofeeder-bom-smt.csv / autofeeder-cpl-smt.csv: SMT-only files (31 placements)
    that exclude the 8 hand-soldered/customer-supplied parts (U1, DISP1, and the THT
    connectors), so the JLCPCB placement machine is never asked to place them.
    - autofeeder-gerbers.zip: rebuilt from the current (23:30) gerbers; the previous zip
    was stale (predated the short + parity fixes) and would have fabbed the old board.
    Flagged for the operator: D1 is an axial DO-41 (THT) ye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
    [autofeeder-bom-smt.csv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]
2026-07-16 Switch to HASL-with-lead + single-sided Economic assembly: move switches to hand-solder
    [autofeeder-bom-smt.csv, autofeeder-bom.csv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]
2026-07-16 f: switch to DIY reflow approach — bare PCBs + stencil from JLCPCB, components from LCSC
    - Rewrote FAB-AND-PARTS.md for bare PCB + stencil ordering workflow
    - Added LCSC BOM CSV with all 22 component lines (SMT + hand-solder)
    - Added cost estimate (~4-63 total, saving ~0-75 vs JLCPCB assembly)
    - Added reflow assembly guide and stencil ordering details
    [autofeeder-lcsc-bom.csv]
2026-07-16 fix: correct 7 LCSC part numbers for BOM tool compatibility
    Fix parts rejected by LCSC BOM matching tool:
    - FS8205A: C2830320 → C908265 (FUXINSEMI, 43k stock)
    - DW01A: C18164398 → C2909013 (FM, 11.6k stock)
    - TP4056: C382139 → C725790 (UMW ESOP-8, 1k stock)
    - USB-C: C165948 → C3020560 (Korean Hroparts, 5k stock)
    - RED LED: C2994782 → C965849 (XINGLIGHT, 67k stock)
    - 1N5817: C507852 → C3759312 (Taiwan Semi DO-41, 5.4k stock)
    - Pin Header 1x4: C42431787 → C2691448 (XFCN, 818k stock)
    Kept C127488 (SKRPADE010) and C158012 (JST XH) as-is —
    tool misreported them but both are valid on LCSC website.
    [autofeeder-lcsc-bom.csv]
2026-07-16 add: simple 2-column LCSC BOM for easier tool matching
    [autofeeder-lcsc-simple.csv]
2026-07-16 fix: add MPN column to simple LCSC BOM
    [autofeeder-lcsc-simple.csv]
2026-07-17 fix: use exact LCSC column header names
    [autofeeder-lcsc-simple.csv]
